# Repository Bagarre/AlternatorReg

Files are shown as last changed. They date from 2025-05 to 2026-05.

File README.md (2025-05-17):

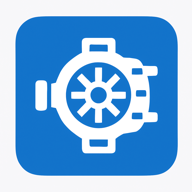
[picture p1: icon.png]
Alternator Icon


# Smart Alternator Regulator

An ESP32-based smart alternator field controller with CANbus integration, web interface, temperature/current derating, and persistent configuration.

---

## 🚀 Features

* Real-time PWM control of alternator field via MOSFET
* Dynamic regulation based on:

  * Target voltage
  * Current limit (via INA260 sensor)
  * Alternator temperature
* CANbus input for engine RPM (PGN 127488)
* NMEA2000 compatible
* Web interface with live status, configuration, and log
* Wi-Fi Access Point fallback ("Alt\_Reg")
* mDNS support: access via `http://alternator.local`
* Config persistence via NVS/Preferences

---

## 📦 Hardware Requirements

| Component | Notes |
| --- | --- |
| ESP32 Dev Module | Any common dev board |
| Adafruit INA260 | Current + Voltage monitor |
| Logic-level N-channel MOSFET | FQP30N06L or similar |
| 10k + 3.3k Resistors | Voltage divider for sensing |
| Flyback diode | Protect MOSFET from inductive spikes |
| 5V Buck converter | For ESP32 power from NMEA2000 |
| CAN transceiver | TJA1051T/3 (Adafruit CAN Pal) |

---

## 🔌 Pinout

### 🧲 MOSFET Gate Drive

To control the alternator field, a logic-level N-channel MOSFET (e.g., FQP30N06L) is used with PWM on the gate.

| Pin | Connects To | Notes |
| --- | --- | --- |
| MOSFET Gate | ESP32 GPIO 25 | Via 100Ω resistor, with 10kΩ pull-down  |
| MOSFET Drain  | Field negative lead | High-current path |
| MOSFET Source | System Ground | Shared with ESP32 and alternator system |

Include a flyback diode (e.g., 1N5819) across the field coil: cathode to 12V, anode to MOSFET drain.

### 📟 INA260 Connections (to ESP32 via I²C)

The Adafruit INA260 provides both current and voltage measurement over I²C.

| INA260 Pin | Connects To | Description |
| --- | --- | --- |
| VIN+ | Alternator Output + | High-side current sense (to load) |
| VIN− | Alternator Output − | Return side of shunt/load |
| SDA | ESP32 GPIO 18 | I²C Data |
| SCL | ESP32 GPIO 19 | I²C Clock |
| GND | ESP32 GND | Common Ground |
| VCC | ESP32 3.3V or 5V | Module Power |

Ensure pull-up resistors (4.7k–10k) are present on SDA and SCL lines if not already on the board.

### 🧷 NMEA 2000 Connector Pinout

NMEA 2000 uses a 5-pin M12 A-coded (DeviceNet Mini) connector:

| Pin | Signal | Description |
| --- | --- | --- |
| 1 | SHLD | Cable Shield |
| 2 | NET-S  | CAN Low |
| 3 | NET-C  | Ground |
| 4 | NET-H  | CAN High |
| 5 | NET-P  | +12V Power Supply |

**Connection to ESP32 via CAN transceiver (e.g., TJA1051T/3):**

* Pin 4 (CAN-H) → CAN\_H on transceiver
* Pin 2 (CAN-L) → CAN\_L on transceiver
* Pin 3 (NET-C) → GND (shared ground with ESP32)
* Pin 5 (NET-P) → 12V input to 5V buck converter → ESP32 VIN/5V
* Transceiver TX/RX ↔ ESP32 GPIO 22 (TX), GPIO 21 (RX)

| Signal | ESP32 Pin |
| --- | --- |
| Field PWM | GPIO 25 |
| Alt Temp ADC | GPIO 34 |
| CAN TX | GPIO 22 |
| CAN RX | GPIO 21 |

---

## 🌐 Web Interface

* Accessible via `http://alternator.local` or IP address
* Three panels:

  * **Status**: live voltage, amps, temp, stage, CAN
  * **Configuration**: editable fields
  * **Network**: WiFi credentials + fallback
  * **Logs**: system events

### Live UI Preview

UI Screenshot

---

## 🔧 API Reference

### `GET /status`

Returns current system metrics.

```json
{
  "voltage": "14.3 V",
  "current": "83.5 A",
  "pwm": "62%",
  "alt_temp": "161°F",
  "batt_temp": "85°F",
  "rpm": "1450",
  "stage": "Bulk",
  "can_status": "OK",
  "last_can": "12:45:12",
  "bms_permission": true,
  "enabled": true
}
```

### `GET /config`

Returns stored configuration.

### `POST /config`

Saves configuration. Example body:

```json
{
  "targetVoltage": "14.4",
  "currentLimit": "90",
  "floatVoltage": "13.5",
  "derateTemp": "90",
  "canInput": true
}
```

### `GET /enable`

Returns `{ "enabled": true/false }`

### `POST /enable`

Sets system enable state:

```json
{
  "enabled": false
}
```

### `POST /network`

Updates Wi-Fi credentials.

```json
{
  "wifiSSID": "MyNetwork",
  "wifiPassword": "MyPassword"
}
```

---

## 📢 NMEA 2000 Messages

### ↓ Received

| PGN | Description | Usage |
| --- | --- | --- |
| 127488 | Engine Parameters (Rapid) | Reads engine RPM (byte 3–4) |

Used to determine if the engine is running above the configured RPM threshold for enabling charge.

### ↑ Transmitted *(planned)*

| PGN | Description | Notes |
| --- | --- | --- |
| TBD | Alternator Temperature | Broadcast temp from sensor  |
| TBD | Charging Status | (Planned) Field PWM %, mode |

## ⚙️ Configuration Defaults (`config.h`)

* Target Voltage: `14.4`
* Current Limit: `90`
* Float Voltage: `13.5`
* Derate Temp: `90`
* CAN Input: `true`

## 📄 Circular Log Feature

A circular log buffer (similar to the bow thruster controller) is planned for tracking:

* Overcurrent incidents (INA260 measured)
* Alternator over-temperature events
* CAN timeouts or field disable triggers
* Manual disables via web UI

Logs will be exposed via `/log` API and persist in RAM (or optionally in SPIFFS for diagnostic dumps). Each entry will include:

* Timestamp
* Event type (e.g., overtemp, field disabled)
* Key data (current, voltage, temp)

## 🧰 Future Improvements

* Dynamic stage transitions (bulk, absorb, float)
* Overcurrent & overtemp logging
* Bluetooth PWA option
* Field soft-off / precharge ramp

---

## 🧑‍💻 Author

**David Ross**
MIT License

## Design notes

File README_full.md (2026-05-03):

# SVBC Alternator Regulator (ESP32 + INA226)

## Overview

This project is a custom alternator regulator intended to replace a Wakespeed WS500.  
It controls alternator field current using PWM based on system voltage, current, and temperature.

Design goals:
- Deterministic startup and fail-safe behavior
- Simple, robust hardware
- External system (Victron Cerbo / DCVV) controls charging strategy
- Regulator only enforces limits and executes commands

---

## Features

- INA226 for voltage and current sensing (no voltage divider)
- DS18B20 sensors for alternator case and ambient temp
- MOSFET low-side field control
- PID voltage regulation
- Temperature derating (linear)
- Soft-start ramp
- RPM gating (startup protection)
- NMEA2000 integration
- Optional WiFi web UI + fallback AP
- Maintenance mode via GPIO

---

## System Architecture

Battery → INA226 → ESP32 → PWM → MOSFET → Field Coil

Sensors:
- DS18B20 (Alt case)
- DS18B20 (Ambient)

Interfaces:
- NMEA2000 (CAN)
- Web UI (WiFi AP fallback)

---

## Hardware Components

### Core
- ESP32 Dev Board
- INA226 module
- 500A shunt
- 2x DS18B20

### Field Control
- IRLZ44N MOSFET
- SR560 diode (preferred)
- 100Ω resistor (gate)
- 10k resistor (pulldown)

### Power
- MPM3610 buck
- 100µF electrolytic
- 0.1µF ceramic

### Protection
- TVS diode (SMBJ24A recommended)

---

## GPIO Mapping

| Function | GPIO |
|---|---|
| Field PWM | 9 |
| DS18B20 | 5 |
| Status LED | 8 |
| Maintenance mode | 12 |
| I2C SDA | 21 |
| I2C SCL | 22 |

---

## Wiring

### Field Control

Field+ → +12V (switched)  
Field- → MOSFET Drain  
Source → Ground  

### Flyback Diode

Stripe → Field+  
Non-stripe → Drain  

### Gate

ESP32 → 100Ω → Gate  
Gate → 10k → Ground  

---

## Startup Sequence

1. LED RGB cycle
2. Sensor checks:
   - INA226
   - DS18B20 (2x)
   - CAN traffic
3. Print result once
4. Enter RUN or FAIL state

---

## LED Behavior

| State | LED |
|---|-----|
| Boot | RGB cycle |
| Checking | Blue |
| OK | Green |
| Warning | Slow red |
| Error | Fast red |

---

## Control Loop

Runs every ~100ms

Error = Target - Measured Voltage  
PID → PWM  

Limits applied:
- Temp derate
- Current limit
- Soft start

---

## Temperature Derating

Start: 80°C  
Stop: 100°C  

Linear scaling

---

## Soft Start

Ramp PWM from 0 → max over configured time

---

## RPM Gate

Min RPM: 2200  
Hold time: 5 minutes  

---

## Safety

Disable field if:
- INA missing
- system disabled
- startup failed

---

## Web UI

Fallback AP:

SSID: SVBC_Alternator  
Password: Nitt4agm2  

Endpoints:
- /api/status
- /api/config
- /api/enable
- /api/network

---

## Notes

- MOSFET tab = Drain (isolate from case)
- DS18B20 invalid: 85C or -127C
- All grounds must be common
- Keep sensor wires away from alternator wiring

---

## Status

Functional prototype  
Needs tuning per alternator

---

## Future

- PID tuning
- RPM from CAN
- Current limiting curves

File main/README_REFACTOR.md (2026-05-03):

# SVBC Alternator Regulator — ESP32 DevKit V1 + INA226 + TJA1051T/3

## Purpose

This project is a custom ESP32-based alternator regulator intended to replace a Wakespeed WS500-style external regulator.

It controls alternator field current with PWM, while using measured bus voltage, alternator current, alternator case temperature, engine-room ambient temperature, RPM/CAN status, and safety limits.

The Victron Cerbo/DCVV system is expected to own charging policy. This regulator executes control and safety limits; it does **not** implement bulk/absorb/float charging stages locally.

## Current hardware target

Primary target board:

- **ESP32 DevKit V1**
- **TJA1051T/3 CAN transceiver** for NMEA2000/TWAI
- **INA226** for voltage/current measurement
- **2x DS18B20** 3-wire digital temperature probes
- **IRLZ44N** or equivalent logic-level MOSFET for alternator field control
- **SR560** Schottky diode across the alternator field coil
- **MPM3610** buck regulator for power

## Why ESP32 DevKit V1

The DevKit V1 has more usable GPIO than a compact XIAO ESP32S3 and is easier to wire, debug, and repair. For a one-off marine controller, that matters more than board size.

## Main functions

- Read voltage and current from INA226
- Read alternator case and ambient temperatures from DS18B20 probes
- Control alternator field with PWM through a low-side MOSFET
- Apply PID voltage regulation
- Apply temperature derating
- Apply hard alternator temperature cutoff with hysteresis
- Apply soft-start ramp
- Require RPM above threshold for a configured hold time before enabling field
- Disable field when Cerbo SOC is above configured threshold, and re-enable below lower threshold
- Expose status/config through the ESP32 web UI
- Run fallback WiFi AP if no configured WiFi connects
- Listen for NMEA2000/TWAI traffic through TJA1051T/3

## GPIO pin map

Defined in `pins.h`.

| Role | ESP32 GPIO | Notes |
|---|---:|---|
| Field PWM output | GPIO25 | Drives MOSFET gate through resistor |
| DS18B20 OneWire data | GPIO26 | Both temperature probes share this bus |
| Maintenance mode switch | GPIO27 | DIP switch to GND enables verbose serial logging |
| INA226 I2C SDA | GPIO21 | ESP32 default SDA |
| INA226 I2C SCL | GPIO22 | ESP32 default SCL |
| CAN/TWAI TX | GPIO5 | Connect to TJA1051 TXD |
| CAN/TWAI RX | GPIO4 | Connect to TJA1051 RXD |

Important: CAN was intentionally moved off GPIO21/22 so it does not conflict with INA226 I2C.

## TJA1051T/3 CAN transceiver wiring

The TJA1051T/3 is the preferred transceiver over TJA1050 because it is compatible with 3.3V ESP32 logic.

Typical wiring:

```text
ESP32 GPIO5  -> TJA1051 TXD
ESP32 GPIO4  -> TJA1051 RXD
ESP32 GND    -> TJA1051 GND
TJA1051 CANH -> NMEA2000 CAN-H
TJA1051 CANL -> NMEA2000 CAN-L
TJA1051 STB  -> GND for normal operation
```

Check your module pin labels. Some modules expose `STB`, `S`, or `EN`. For a standard TJA1051 standby pin, tie it LOW/GND for normal operation.

Only install a 120 ohm CAN termination resistor if this node is at the physical end of the backbone and the backbone is not already properly terminated. A normal NMEA2000 backbone already has two terminators, one at each end.

## INA226 wiring

The INA226 measures both bus voltage and shunt voltage/current. The old voltage-divider method should not be used.

```text
ESP32 3.3V  -> INA226 VCC
ESP32 GND   -> INA226 GND
ESP32 GPIO21 -> INA226 SDA
ESP32 GPIO22 -> INA226 SCL
```

Shunt wiring:

```text
Battery negative / bus side ----[ SHUNT ]---- alternator/load side
INA226 IN+ -> battery/bus side of shunt
INA226 IN- -> alternator/load side of shunt
```

Use short Kelvin sense leads from the shunt sense screws. Twisted pair is recommended.

Default shunt assumption:

```text
500A / 50mV shunt = 0.0001 ohm
```

This is defined in `sensors.cpp` as `SHUNT_RESISTANCE_OHM`.

## DS18B20 temperature wiring

Both DS18B20 probes share one OneWire bus.

```text
DS18B20 VCC  -> 3.3V
DS18B20 GND  -> GND
DS18B20 DATA -> GPIO26
4.7k resistor from DATA to 3.3V
```

Sensor index convention:

```text
Index 0 = alternator case temperature
Index 1 = engine room ambient temperature
```

For long engine-room runs, use 3-wire mode, not parasite power. 15 ft is acceptable if routed cleanly. Keep DS18B20 wiring away from alternator output and starter cables.

Invalid DS18B20 values are treated as missing/faulted:

```text
-127°C = disconnected
85°C   = power-on/default conversion value, ignored
```

## Field control hardware

The regulator uses low-side MOSFET field control.

```text
Switched +12V -> Alternator Field+
Alternator Field- -> MOSFET Drain
MOSFET Source -> Ground
```

Gate network:

```text
ESP32 GPIO25 -> 100 ohm resistor -> MOSFET Gate
MOSFET Gate -> 10k resistor -> Ground
```

Flyback diode across the field coil:

```text
SR560 cathode/stripe -> Field+
SR560 anode          -> MOSFET drain / Field-
```

MOSFET recommendation:

- IRLZ44N is acceptable and available
- IRLB3034 or similar lower-Rds MOSFET is better if buying parts

MOSFET mounting warning:

- TO-220 tab is usually connected to Drain
- Do not bolt the tab directly to the aluminum case unless using an insulating thermal pad and shoulder washer

## Power

Use the MPM3610 or similar buck converter to power the ESP32 from boat 12V.

Recommended:

```text
12V input -> small fuse -> MPM3610 -> ESP32 VIN/5V
GND common between ESP32, INA226, field driver, alternator/battery negative, and CAN transceiver
```

Recommended capacitors:

- 100uF electrolytic on 12V input
- 0.1uF ceramic near power input
- 10uF + 0.1uF near INA226 if wiring is noisy

Recommended protection:

- TVS diode such as SMBJ24A on 12V input

## Startup check routine

On boot the firmware performs a one-time startup check and prints clear serial output.

Checks:

- INA226 voltage/current monitor present
- Alternator DS18B20 case temperature valid
- Engine-room DS18B20 ambient temperature valid
- N2K/CAN traffic present, if `canInput` is enabled

Example failure output:

```text
=== Alternator Regulator Startup Check ===
Checking INA226 voltage/current monitor... ERROR / not present
Checking alternator DS18B20 case temp... ERROR / not present
Checking engine room DS18B20 ambient temp... ERROR / not present
Checking N2K/CAN input... ERROR / not present
------------------------------------------
System check complete: unable to continue normal regulation.
Maintenance mode: disabled.
==========================================
```

The startup check is intentionally quiet after initial report unless maintenance mode is enabled.

## Maintenance mode

GPIO27 uses `INPUT_PULLUP`.

```text
DIP switch open        = normal quiet mode
DIP switch to GND      = maintenance / verbose serial logging
```

Use this when the case is open and a laptop is plugged into USB.

## NMEA2000 / CAN usage currently

The code uses ESP32 TWAI directly through `driver/twai.h`.

Current N2K functions:

- Detect bus traffic for startup sanity checks
- Read engine RPM from PGN `127488` where available
- Read battery SOC from PGN `127506` for Cerbo SOC inhibit

SOC inhibit logic:

- Default enabled
- Disable field at or above 95% SOC
- Re-enable only at or below 90% SOC
- Uses hysteresis to prevent rapid cycling

This is a protective fallback. Long term, proper Cerbo/DCVV control should provide voltage target/current limit/charge permission explicitly.

## Web UI

Fallback AP defaults:

```text
SSID: SVBC_Alternator
Password: Nitt4agm2
```

The UI is served from `data/` uploaded to the ESP32 filesystem. If the filesystem page is missing, the firmware includes a fallback page.

Common endpoints:

```text
GET  /api/status
GET  /api/config
POST /api/config
GET  /api/enable
POST /api/enable
GET  /api/log
POST /api/network
POST /api/network/reset
POST /api/reboot
```

## Web UI organization

The UI is organized like the charger-control UI:

1. Operational data at top
2. Settings below
3. Network settings
4. Verbose/debug/raw status at bottom

## Config persistence

Configuration is stored in ESP32 flash through the config store.

Expected persistent settings include:

- Target voltage
- Current limit
- PID constants
- Derate start/stop temps
- Hard cutoff/reset temps
- Soft-start seconds
- Min start RPM
- RPM hold seconds
- SOC inhibit enable/high/low thresholds
- CAN input enable
- WiFi credentials

Runtime state does not persist, including:

- Field enabled state
- PID integral
- active latches/faults
- CAN online state

## Safety behavior

Field is forced off if:

- INA226 is missing or invalid
- Startup check fails
- System is disabled
- Alternator temperature sensor fails
- Alternator hard temperature cutoff is latched
- Cerbo SOC inhibit is latched
- Required RPM gate has not been satisfied

## Temperature behavior

Derating:

- Reduces field output linearly between configured derate start/stop temperatures

Hard cutoff:

- Forces field off at configured hard cutoff temperature
- Re-enables only after alternator temp falls below reset temperature

This prevents chatter near the cutoff threshold.

## Bench testing notes

Minimum useful bench setup:

- ESP32 DevKit V1
- INA226 connected over I2C
- DS18B20 probes connected to GPIO26
- MOSFET output driving LED/test load instead of real alternator field
- Serial monitor open at 115200
- Web UI open through fallback AP or configured WiFi

Before alternator testing, verify:

- INA226 reports realistic bus voltage
- Current reads near zero at rest
- DS18B20 sensors report sane values
- Removing a temp sensor causes fault/warning
- Field PWM goes to zero when INA is missing
- Field PWM goes to zero on hard temp cutoff
- SOC inhibit latches/re-enables correctly when simulated

## Known next steps

- Tune PID gains on the actual alternator
- Verify field PWM frequency and MOSFET heating under real field load
- Verify RPM PGN parsing from the actual engine/Cerbo/N2K source
- Decide whether to implement explicit Cerbo/DCVV voltage/current/permission control instead of SOC-only fallback
- Add proper sensor addressing for DS18B20 if probe order ever swaps

## Current board support summary

This package is now configured for:

```text
Board: ESP32 DevKit V1
CAN: external TJA1051T/3 transceiver
Current/Voltage: INA226 over I2C
Temps: DS18B20 OneWire
Field: MOSFET low-side PWM
```

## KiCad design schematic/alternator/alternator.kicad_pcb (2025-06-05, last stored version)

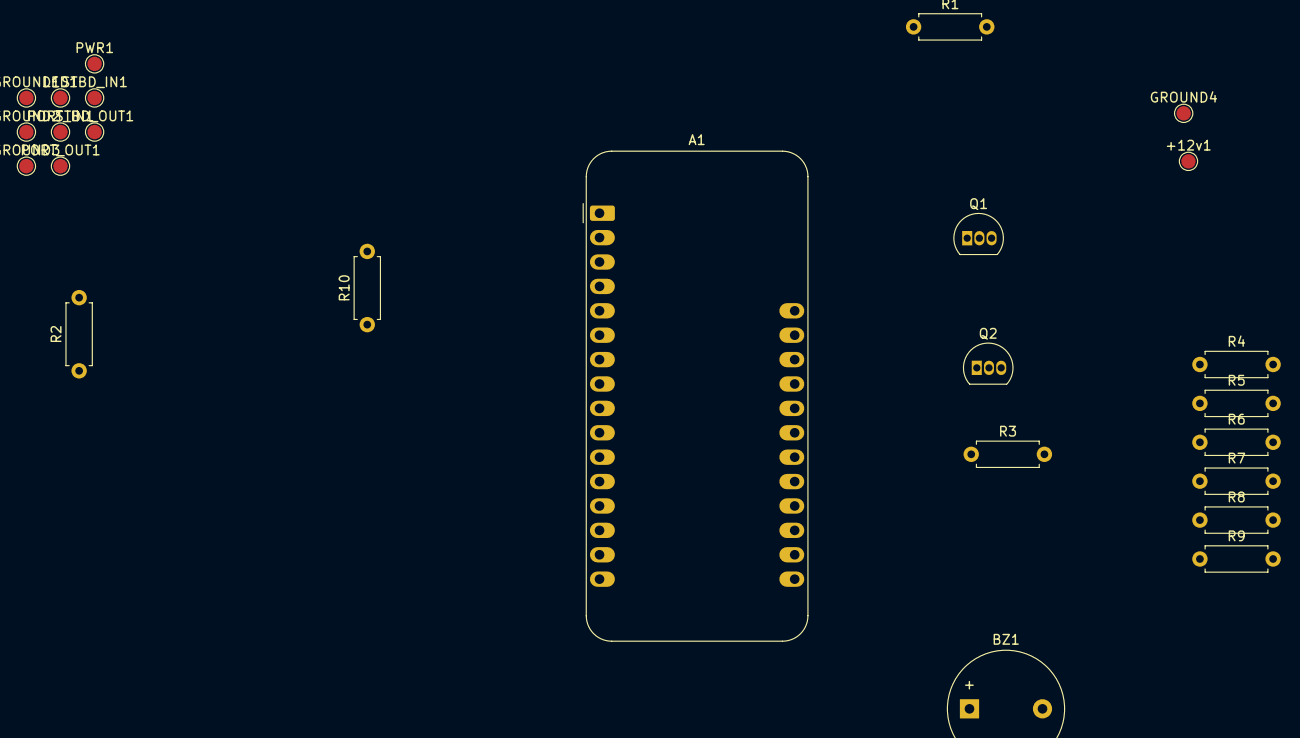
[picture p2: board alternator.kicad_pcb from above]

Board: 2 copper layers, 25 parts (0 on the bottom side), 16 nets, no tracks yet.

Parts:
+12v1: TESTPAD; TestPoint_Pad_D1.5mm
A1: Metro; Adafruit_Feather
BZ1: Buzzer; Buzzer_12x9.5RM7.6
GROUND1, GROUND2, GROUND3, GROUND4: TESTPAD; TestPoint_Pad_D1.5mm
LED1: TESTPAD; TestPoint_Pad_D1.5mm
PORT_IN1: TESTPAD; TestPoint_Pad_D1.5mm
PORT_OUT1: TESTPAD; TestPoint_Pad_D1.5mm
PWR1: TESTPAD; TestPoint_Pad_D1.5mm
Q1, Q2: PNP; TO-92L_Inline
R1, R3, R5, R8, R9: 10k; R_Axial_DIN0207_L6.3mm_D2.5mm_P7.62mm_Horizontal
R2, R4, R10: 4.7k; R_Axial_DIN0207_L6.3mm_D2.5mm_P7.62mm_Horizontal
R6, R7: 1k; R_Axial_DIN0207_L6.3mm_D2.5mm_P7.62mm_Horizontal
STBD_IN1: TESTPAD; TestPoint_Pad_D1.5mm
STBD_OUT1: TESTPAD; TestPoint_Pad_D1.5mm

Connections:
unnamed: A1.5 (A0), R9.2, R10.1
unnamed: A1.6 (A1), R3.2, R4.1
unnamed: A1.7 (A2), R1.2, R2.1
unnamed: A1.19 (D0), LED1.1 (Pad)
unnamed: A1.20 (D1), PWR1.1 (Pad)
unnamed: A1.21 (D2), STBD_IN1.1 (Pad)
unnamed: A1.22 (D3), PORT_IN1.1 (Pad)
unnamed: A1.23 (D4), R5.1, R6.1
unnamed: A1.24 (D5), R7.1, R8.1
unnamed: A1.25 (D6), BZ1.1 (+)
unnamed: A1.4 (GND), BZ1.2 (-), GROUND1.1 (Pad), GROUND2.1 (Pad), GROUND3.1 (Pad), GROUND4.1 (Pad), R2.2, R4.2, R10.2
unnamed: +12v1.1 (Pad), A1.28 (VBAT), Q1.3 (E), Q2.3 (E), R5.2, R8.2, R9.1
unnamed: Q1.2 (B), R6.2
unnamed: Q1.1 (C), R1.1, STBD_OUT1.1 (Pad)
unnamed: Q2.2 (B), R7.2
unnamed: PORT_OUT1.1 (Pad), Q2.1 (C), R3.1

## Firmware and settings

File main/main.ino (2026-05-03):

#include <Arduino.h>
#include <ESPAsyncWebServer.h>
#include <ESPmDNS.h>

#include "app_types.h"
#include "config_store.h"
#include "log_buffer.h"
#include "wifi_manager.h"
#include "sensors.h"
#include "field_driver.h"
#include "can_bus.h"
#include "control_loop.h"
#include "web_server.h"

AppConfig config;
AppState state;
AsyncWebServer server(80);

namespace {
void printCheckLine(const char* label, bool ok) {
  Serial.print("Checking ");
  Serial.print(label);
  Serial.print("... ");
  Serial.println(ok ? "OK" : "ERROR / not present");
}

void runStartupCheck() {
  Serial.println();
  Serial.println("=== Alternator Regulator Startup Check ===");

  printCheckLine("INA226 voltage/current monitor", state.ina226Available);
  printCheckLine("alternator DS18B20 case temp", state.altTempSensorOk);
  printCheckLine("engine room DS18B20 ambient temp", state.engineRoomTempSensorOk);

  if (config.canInput) {
    printCheckLine("N2K/CAN input", state.canOnline);
  } else {
    Serial.println("Checking N2K/CAN input... SKIPPED - canInput=false");
  }

  Serial.println("------------------------------------------");

  const bool canOk = !config.canInput || state.canOnline;
  state.startupCheckOk = state.ina226Available && state.altTempSensorOk && state.engineRoomTempSensorOk && canOk;
  state.startupCheckComplete = true;

  if (state.startupCheckOk) {
    state.startupStatus = "OK";
    Serial.println("System check complete: OK.");
    addLog("Startup check OK", state.busVoltage, state.chargeCurrent, state.alternatorTempC);
  } else {
    state.startupStatus = "Fault";
    Serial.println("System check complete: unable to continue normal regulation.");
    addLog("Startup check failed", state.busVoltage, state.chargeCurrent, state.alternatorTempC);
  }

  if (maintenanceMode()) {
    Serial.println("Maintenance mode: ENABLED - verbose serial logging active.");
  } else {
    Serial.println("Maintenance mode: disabled.");
  }

  Serial.println("==========================================");
  Serial.println();
}

void printVerboseStatus() {
  if (!maintenanceMode()) return;

  static unsigned long lastVerboseMs = 0;
  const unsigned long now = millis();
  if (now - lastVerboseMs < 2000) return;
  lastVerboseMs = now;

  Serial.print("STATUS ");
  Serial.print("INA="); Serial.print(state.ina226Available ? "OK" : "FAIL");
  Serial.print(" CAN="); Serial.print(state.canOnline ? "OK" : "FAIL");
  Serial.print(" V="); if (isfinite(state.busVoltage)) Serial.print(state.busVoltage, 3); else Serial.print("NA");
  Serial.print(" I="); if (isfinite(state.chargeCurrent)) Serial.print(state.chargeCurrent, 2); else Serial.print("NA");
  Serial.print(" AltT="); if (state.altTempSensorOk) Serial.print(state.alternatorTempC, 1); else Serial.print("FAIL");
  Serial.print(" AmbT="); if (state.engineRoomTempSensorOk) Serial.print(state.engineRoomTempC, 1); else Serial.print("FAIL");
  Serial.print(" PWM="); Serial.print(state.pwmDuty);
  Serial.print(" Stage="); Serial.print(state.stage);
  Serial.print(" Disable="); Serial.println(state.lastDisableReason);
}
}

void setup() {
  Serial.begin(115200);
  delay(200);

  state.bootMillis = millis();
  initLogBuffer();
  addLog("Boot");
  Serial.println("Alternator Regulator boot");

  loadConfig(config);

  initSensors(state);
  sampleSensors(state);

  initFieldDriver();
  initControlLoop();

  setupWiFi(config);
  if (MDNS.begin("alternator")) {
    addLog("mDNS started");
  }

  setupWebServer(server, config, state);
  setupCAN(state);

  // Give CAN a short chance to see traffic before the one-time startup check.
  const unsigned long startWait = millis();
  while (millis() - startWait < 1500) {
    processCANMessages(config, state);
    delay(10);
  }

  runStartupCheck();
}

void loop() {
  sampleSensors(state);
  processCANMessages(config, state);
  runControlLoop(config, state);
  printVerboseStatus();
}

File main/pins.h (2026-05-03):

#pragma once

// ESP32 DevKit V1 + external TJA1051T/3 CAN transceiver pin map.
// Adjust here if your board wiring changes.
//
// IMPORTANT:
// - ESP32 default I2C pins are SDA=21 and SCL=22.
// - Do NOT use GPIO21/22 for CAN when using INA226 on I2C.
// - TJA1051T/3 STB/standby pin must be tied LOW/GND for normal operation.

// Low-side MOSFET gate drive for alternator field PWM.
constexpr int FIELD_PIN = 25;

// OneWire bus for both DS18B20 sensors:
//   index 0 = alternator case temp
//   index 1 = engine room ambient temp
constexpr int ONE_WIRE_PIN = 26;

// DIP switch to GND enables verbose maintenance logging over USB serial.
constexpr int MAINTENANCE_MODE_PIN = 27;

// INA226 I2C bus pins.
constexpr int I2C_SDA_PIN = 21;
constexpr int I2C_SCL_PIN = 22;

// ESP32 TWAI/CAN pins to external TJA1051T/3 transceiver.
// Wiring:
//   GPIO5 -> TJA1051 TXD
//   GPIO4 -> TJA1051 RXD
//   TJA1051 CANH/CANL -> NMEA2000 backbone
//   TJA1051 STB -> GND
constexpr int CAN_TX_PIN = 5;
constexpr int CAN_RX_PIN = 4;

constexpr int PWM_CHANNEL = 0;
constexpr int PWM_FREQ_HZ = 250;
constexpr int PWM_RESOLUTION_BITS = 8;

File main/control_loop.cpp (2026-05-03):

#include "control_loop.h"
#include "field_driver.h"
#include "log_buffer.h"
#include <Arduino.h>
#include <math.h>

namespace {
constexpr unsigned long CONTROL_INTERVAL_MS = 100;
constexpr uint8_t DUTY_MAX = 255;
constexpr uint8_t DUTY_FALL_PER_TICK = 12;
constexpr float PID_INTEGRAL_LIMIT = 80.0f;
constexpr float CURRENT_LIMIT_DERATE_BAND_A = 25.0f;
constexpr float MIN_DERATE_SPAN_C = 2.0f;

uint8_t clampDuty(int value) {
  if (value < 0) return 0;
  if (value > DUTY_MAX) return DUTY_MAX;
  return static_cast<uint8_t>(value);
}

uint8_t applyFallLimit(uint8_t currentDuty, uint8_t requestedDuty) {
  // Upward ramp is handled by the soft-start cap. Downward movement is allowed
  // to be faster for safety, but not an instant cliff unless a hard fault occurs.
  if (requestedDuty >= currentDuty) return requestedDuty;
  return static_cast<uint8_t>(max<int>(currentDuty - DUTY_FALL_PER_TICK, requestedDuty));
}

bool rpmAllowsCharge(const AppConfig& config, AppState& state) {
  const unsigned long now = millis();

  if (!config.canInput) {
    return true;
  }

  if (state.currentRPM >= config.minStartRPM) {
    if (state.rpmAboveThresholdStartMillis == 0) {
      state.rpmAboveThresholdStartMillis = now;
    }
  } else {
    state.rpmAboveThresholdStartMillis = 0;
    state.regulationStartMillis = 0;
  }

  if (state.rpmAboveThresholdStartMillis == 0) {
    return false;
  }

  return (now - state.rpmAboveThresholdStartMillis) >= static_cast<unsigned long>(config.rpmHoldSeconds * 1000.0f);
}

uint8_t pidVoltageDuty(const AppConfig& config, AppState& state, float dtSeconds) {
  if (!isfinite(state.busVoltage) || dtSeconds <= 0.0f) {
    return 0;
  }

  const float error = config.targetVoltage - state.busVoltage;

  // Anti-windup: only integrate when we are not already badly over voltage.
  if (error > -0.15f) {
    state.pidIntegral += error * dtSeconds;
    state.pidIntegral = constrain(state.pidIntegral, -PID_INTEGRAL_LIMIT, PID_INTEGRAL_LIMIT);
  }

  const float derivative = (error - state.lastPidError) / dtSeconds;
  state.lastPidError = error;

  float output = (config.pidKp * error) +
                 (config.pidKi * state.pidIntegral) +
                 (config.pidKd * derivative);

  // Bias around current duty so the PID trims field instead of acting like a
  // bang-bang controller from zero every tick.
  output += state.pwmDuty;

  return clampDuty(static_cast<int>(roundf(output)));
}

uint8_t currentLimitCap(const AppConfig& config, const AppState& state) {
  if (!isfinite(state.chargeCurrent)) return 0;
  if (config.currentLimit <= 0.0f) return DUTY_MAX;
  if (state.chargeCurrent <= config.currentLimit) return DUTY_MAX;

  const float over = state.chargeCurrent - config.currentLimit;
  const float ratio = 1.0f - constrain(over / CURRENT_LIMIT_DERATE_BAND_A, 0.0f, 1.0f);
  return clampDuty(static_cast<int>(roundf(DUTY_MAX * ratio)));
}

uint8_t tempDerateCap(const AppConfig& config, const AppState& state) {
  if (!state.altTempSensorOk || !isfinite(state.alternatorTempC)) return 0;

  const float startC = config.derateStartTempC;
  const float stopC = max(config.derateStopTempC, startC + MIN_DERATE_SPAN_C);

  if (state.alternatorTempC <= startC) return DUTY_MAX;
  if (state.alternatorTempC >= stopC) return 0;

  const float ratio = (stopC - state.alternatorTempC) / (stopC - startC);
  return clampDuty(static_cast<int>(roundf(DUTY_MAX * constrain(ratio, 0.0f, 1.0f))));
}

void updateHardTempCutoff(const AppConfig& config, AppState& state) {
  if (!state.altTempSensorOk || !isfinite(state.alternatorTempC)) {
    state.alternatorOverTemp = false;
    return;
  }

  const float cutoffC = max(config.hardCutoffTempC, config.derateStopTempC);
  const float resetC = min(config.hardCutoffResetTempC, cutoffC - 1.0f);

  if (!state.alternatorTempCutoffLatched && state.alternatorTempC >= cutoffC) {
    state.alternatorTempCutoffLatched = true;
    addLog("Alternator hard temp cutoff tripped", state.busVoltage, state.chargeCurrent, state.alternatorTempC);
  } else if (state.alternatorTempCutoffLatched && state.alternatorTempC <= resetC) {
    state.alternatorTempCutoffLatched = false;
    addLog("Alternator hard temp cutoff cleared", state.busVoltage, state.chargeCurrent, state.alternatorTempC);
  }

  state.alternatorOverTemp = state.alternatorTempCutoffLatched;
}


void updateSocInhibit(const AppConfig& config, AppState& state) {
  if (!config.socInhibitEnabled) {
    if (state.socInhibitLatched) {
      addLog("SOC inhibit disabled", state.busVoltage, state.chargeCurrent, state.alternatorTempC);
    }
    state.socInhibitLatched = false;
    return;
  }

  if (!state.cerboSocValid || !isfinite(state.cerboSocPercent)) {
    return;
  }

  const float highPct = constrain(config.socInhibitHighPercent, 0.0f, 100.0f);
  const float lowPct = constrain(min(config.socInhibitLowPercent, highPct - 1.0f), 0.0f, 99.0f);

  if (!state.socInhibitLatched && state.cerboSocPercent >= highPct) {
    state.socInhibitLatched = true;
    addLog("SOC inhibit tripped", state.busVoltage, state.chargeCurrent, state.alternatorTempC);
  } else if (state.socInhibitLatched && state.cerboSocPercent <= lowPct) {
    state.socInhibitLatched = false;
    addLog("SOC inhibit cleared", state.busVoltage, state.chargeCurrent, state.alternatorTempC);
  }
}

uint8_t softStartCap(const AppConfig& config, AppState& state) {
  if (config.softStartSeconds <= 0.0f) return DUTY_MAX;

  const unsigned long now = millis();
  if (state.regulationStartMillis == 0) {
    state.regulationStartMillis = now;
  }

  const float elapsed = (now - state.regulationStartMillis) / 1000.0f;
  const float ratio = constrain(elapsed / config.softStartSeconds, 0.0f, 1.0f);
  return clampDuty(static_cast<int>(roundf(DUTY_MAX * ratio)));
}

void resetPid(AppState& state) {
  state.pidIntegral = 0.0f;
  state.lastPidError = 0.0f;
  state.regulationStartMillis = 0;
  state.pidRequestedDuty = 0;
  state.tempDutyCap = DUTY_MAX;
  state.hardTempDutyCap = DUTY_MAX;
  state.currentDutyCap = DUTY_MAX;
  state.softStartDutyCap = DUTY_MAX;
}
}

void initControlLoop() {
}

void disableField(AppState& state, const String& reason) {
  disableFieldOutput();
  state.pwmDuty = 0;
  state.requestedDuty = 0;
  resetPid(state);
  if (state.fieldEnabled || state.lastDisableReason != reason) {
    addLog("Field disabled: " + reason, state.busVoltage, state.chargeCurrent, state.alternatorTempC);
  }
  state.fieldEnabled = false;
  state.stage = "Idle";
  state.lastDisableReason = reason;
}
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

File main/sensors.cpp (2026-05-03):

#include "sensors.h"
#include "pins.h"
#include "log_buffer.h"
#include <Arduino.h>
#include <Wire.h>
#include <OneWire.h>
#include <DallasTemperature.h>
#include <math.h>

namespace {
constexpr uint8_t INA226_I2C_ADDR = 0x40;
constexpr float SHUNT_RESISTANCE_OHM = 0.0001f; // 500A/50mV shunt. Change if needed.
constexpr float CURRENT_ZERO_DEADBAND_A = 0.05f;
constexpr uint8_t DS18B20_ALT_INDEX = 0;
constexpr uint8_t DS18B20_ENGINE_ROOM_INDEX = 1;

OneWire oneWire(ONE_WIRE_PIN);
DallasTemperature tempSensors(&oneWire);

class INA226Simple {
public:
  explicit INA226Simple(uint8_t address) : addr(address) {}

  bool begin() {
    Wire.begin(I2C_SDA_PIN, I2C_SCL_PIN);
    // AVG=16 samples, VBUSCT=1.1ms, VSHCT=1.1ms, mode=shunt+bus continuous.
    writeRegister16(0x00, 0x4527);
    delay(5);
    uint16_t bus = 0;
    return readRegister16(0x02, bus);
  }

  bool read(float& busVoltageV, float& shuntVoltageMV, float& currentA) {
    uint16_t rawBus = 0;
    uint16_t rawShuntU = 0;
    if (!readRegister16(0x02, rawBus)) return false;
    if (!readRegister16(0x01, rawShuntU)) return false;

    const int16_t rawShunt = static_cast<int16_t>(rawShuntU);
    busVoltageV = rawBus * 0.00125f;
    shuntVoltageMV = rawShunt * 0.0025f;
    currentA = (shuntVoltageMV / 1000.0f) / SHUNT_RESISTANCE_OHM;

    if (fabs(currentA) < CURRENT_ZERO_DEADBAND_A) {
      currentA = 0.0f;
    }
    return true;
  }

private:
  uint8_t addr;

  bool writeRegister16(uint8_t reg, uint16_t value) {
    Wire.beginTransmission(addr);
    Wire.write(reg);
    Wire.write(static_cast<uint8_t>(value >> 8));
    Wire.write(static_cast<uint8_t>(value & 0xFF));
    return Wire.endTransmission() == 0;
  }

  bool readRegister16(uint8_t reg, uint16_t& value) {
    Wire.beginTransmission(addr);
    Wire.write(reg);
    if (Wire.endTransmission(false) != 0) return false;

    if (Wire.requestFrom(static_cast<int>(addr), 2) != 2) return false;
    const uint8_t msb = Wire.read();
    const uint8_t lsb = Wire.read();
    value = (static_cast<uint16_t>(msb) << 8) | lsb;
    return true;
  }
};

INA226Simple ina226(INA226_I2C_ADDR);

bool prevInaOk = false;
bool prevAltTempOk = false;
bool prevEngineRoomTempOk = false;
}

bool maintenanceMode() {
  return digitalRead(MAINTENANCE_MODE_PIN) == LOW;
}

bool validDs18b20Temp(float tempC) {
  // DEVICE_DISCONNECTED_C is normally -127C. 85C is the DS18B20 power-on value
  // before a real conversion completes, so do not count it as valid.
  return isfinite(tempC) && tempC != DEVICE_DISCONNECTED_C && tempC != 85.0f && tempC > -55.0f && tempC < 125.0f;
}

void initSensors(AppState& state) {
  pinMode(MAINTENANCE_MODE_PIN, INPUT_PULLUP);

  Wire.begin(I2C_SDA_PIN, I2C_SCL_PIN);
  state.ina226Available = ina226.begin();

  tempSensors.begin();
  tempSensors.setWaitForConversion(false);
  tempSensors.requestTemperatures();
  delay(750);

  prevInaOk = state.ina226Available;
  prevAltTempOk = false;
  prevEngineRoomTempOk = false;
}

void sampleSensors(AppState& state) {
  float busV = NAN;
  float shuntMV = NAN;
  float currentA = NAN;

  state.ina226Available = ina226.read(busV, shuntMV, currentA);
  if (state.ina226Available) {
    state.busVoltage = busV;
    state.shuntVoltageMV = shuntMV;
    state.chargeCurrent = currentA;
  } else {
    state.busVoltage = NAN;
    state.shuntVoltageMV = NAN;
    state.chargeCurrent = NAN;
  }

  state.alternatorTempC = tempSensors.getTempCByIndex(DS18B20_ALT_INDEX);
  state.engineRoomTempC = tempSensors.getTempCByIndex(DS18B20_ENGINE_ROOM_INDEX);
  state.altTempSensorOk = validDs18b20Temp(state.alternatorTempC);
  state.engineRoomTempSensorOk = validDs18b20Temp(state.engineRoomTempC);

  tempSensors.requestTemperatures();

  if (state.ina226Available != prevInaOk) {
    addLog(state.ina226Available ? "INA226 OK" : "INA226 missing");
    prevInaOk = state.ina226Available;
  }
  if (state.altTempSensorOk != prevAltTempOk) {
    addLog(state.altTempSensorOk ? "Alternator temp sensor OK" : "Alternator temp sensor missing");
    prevAltTempOk = state.altTempSensorOk;
  }
  if (state.engineRoomTempSensorOk != prevEngineRoomTempOk) {
    addLog(state.engineRoomTempSensorOk ? "Engine room temp sensor OK" : "Engine room temp sensor missing");
    prevEngineRoomTempOk = state.engineRoomTempSensorOk;
  }
}

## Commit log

2025-05-17 Another push
    [alternator.kicad_pcb, alternator.kicad_sch]
2026-05-03 refactors
    yeah
    [alternator.kicad_pcb, alternator.kicad_sch]
